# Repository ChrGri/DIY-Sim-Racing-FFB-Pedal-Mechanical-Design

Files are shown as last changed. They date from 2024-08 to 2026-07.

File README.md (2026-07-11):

<p align="center">
  DIY Sim Racing FFB Pedal Banner
</p>

# DIY-Sim-Racing-FFB-Pedal-Mechanical-Design
If you're used to standard spring or damper-based pedals with rumble motors attached, a force-feedback pedal is the next step. It uses a high power servo attached to a linear rail to control the motion of the pedal. This allows you to change how the pedal feels with a few changes on your PC, whether that's braking pressure, response or travel or the thottle weight or stiffness. You can even use profiles to build different "feels" for different cars, switching profiles between cars to give each vehicle a different driving experience. Additionally, since the pedal movement is controlled, the feedback it can produce is totally different - imaging feeling ABS feedback moving the pedal, the kick of the gear change through the throttle or feedback from road bumps through the pedals. It's an experience like no other! If that sounds like something you want to build for yourself, then read on! This project documents people who want to design and/or build their own force-feedback pedal. 

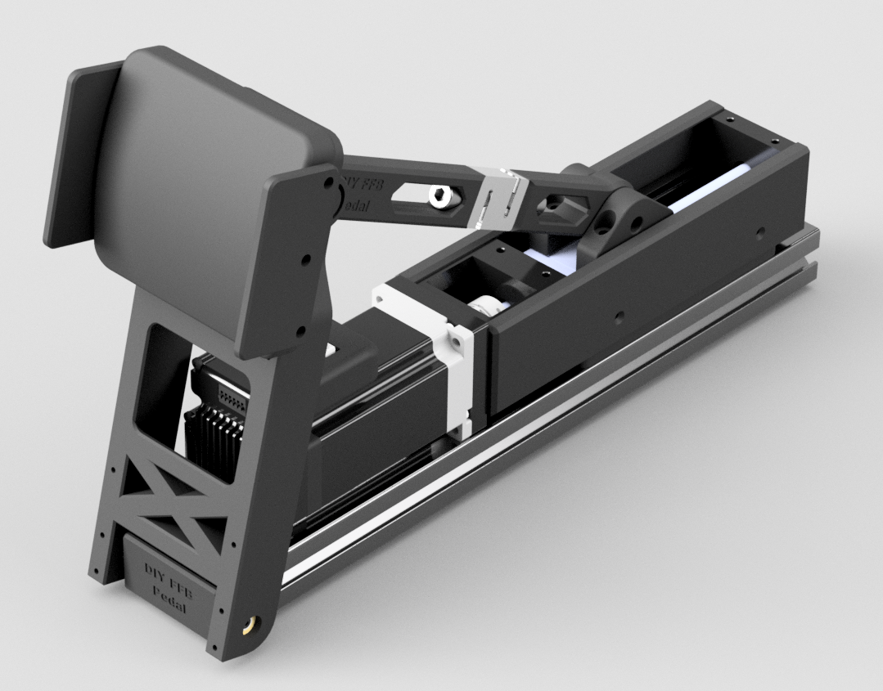
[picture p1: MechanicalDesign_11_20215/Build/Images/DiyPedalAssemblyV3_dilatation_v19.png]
Current iteration of pedal design, using more expensive components, such as JKK60 linear rails, DYLY-107 loadcell, 3080 aluminium profile <br> .

The current iteration of the electronics are depicted below <br>
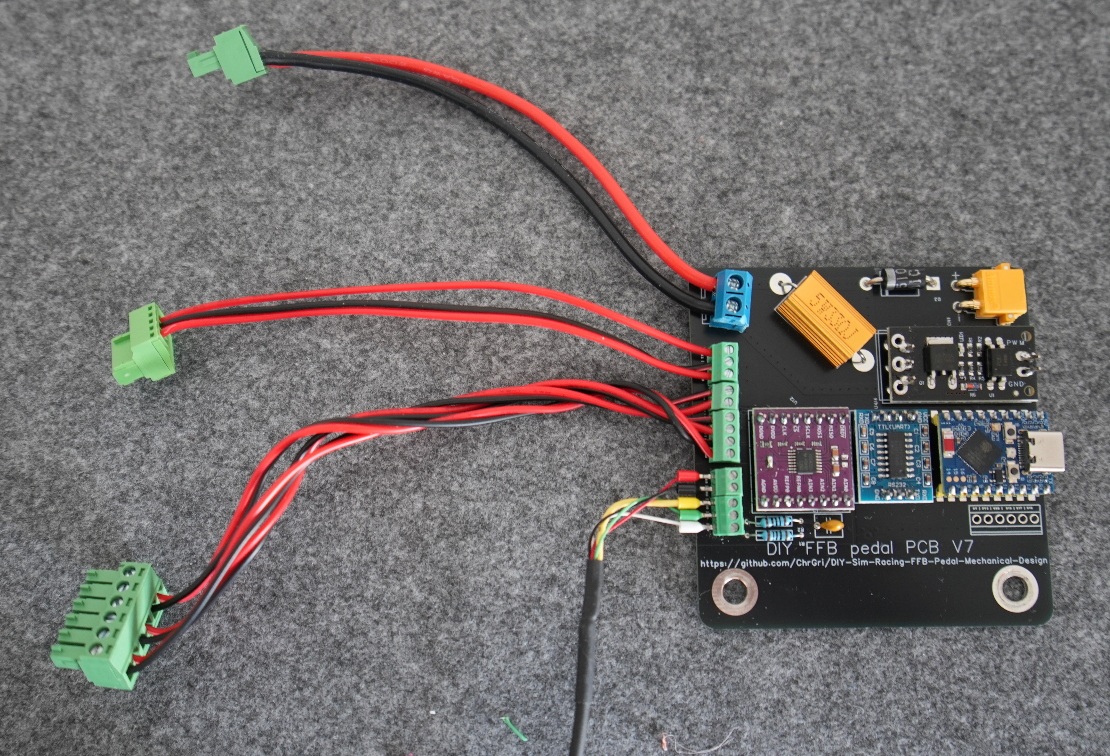
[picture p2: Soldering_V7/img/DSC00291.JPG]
.

This is V7 of the PCB design and compared to previous versions, it offers
- better loadcell reading signal-to-noise-ratio (SNR) due to RC-filter design and better wire routing
- smaller form factor
- lower costs (since ESP32 S3 zero/mini is cheaper)
- better wire management.

> [!TIP]
> **Disclaimer** This repository documents my research progress. I wanted to understand the necessary signal processing and control theory algorithms behind such a device. 

> [!WARNING]
> The FFB pedal is a robot and can be dangerous. Please watch [The Terminator](https://en.wikipedia.org/wiki/The_Terminator) before continuing. If not interacted with care, it may cause harm. I'm not responsible for any harm caused by this design suggestion. Use responsibly and at your own risk.

# Project repositories
This project has been divided into multiple repositories, each with differt purposes. The mechanical design repository provides the information you need to build the mechanics of ChrGri's pedal. It's not the only design, but it's strong and reliable. There are more options on the Wiki, and you can find even more designs on the Discord server. The Software repo (this repo) discusses how to select, order and connect the electronics, flash the firmware and get the pedal up and running. The final repo, contains designs for the recommended circuit boards that control the pedal.
| Description           |  Link |
:------------------------- | :------------------------- |
| ChrGri's mechanical and electrical design | https://github.com/ChrGri/DIY-Sim-Racing-FFB-Pedal-Mechanical-Design |
| Software (firmware, SimHub plugin, ...) |https://github.com/ChrGri/DIY-Sim-Racing-FFB-Pedal |
| Control Board and Power Board design | https://github.com/gilphilbert/DIY-Sim-Racing-FFB-Pedal-PCBs |

# Support the team
We :heart: doing research. New hardware (e.g. oscilloscopes, logic analyzers, servos, PCBs) is very expensive. Feel free to support us and thus fasten up the research activity.

Dev | captainchris | tcfshcrw | gilphilbert
--- | --- |--- |-- 
Buy me a coffee |  |  |    | 
Ko-fi |  | |   |

# License
Shield: [][cc-by-nc-sa]

This work is licensed under a
[Creative Commons Attribution-NonCommercial-ShareAlike 4.0 International License][cc-by-nc-sa].

[][cc-by-nc-sa]

The reason for that license selection is that at some point in time, individuals start
- to steal the sources and binaries and sell them on the internet
- mass production of FFB pedals in their living rooms to make money by taking parts from this project and Simucubes design files.
  
All that, without contributing anything to this project.

[cc-by-nc-sa]: http://creativecommons.org/licenses/by-nc-sa/4.0/
[cc-by-nc-sa-image]: https://licensebuttons.net/l/by-nc-sa/4.0/88x31.png
[cc-by-nc-sa-shield]: https://img.shields.io/badge/License-CC%20BY--NC--SA%204.0-lightgrey.svg

# BOM
The price of one pedal is about 250€-400€. <br>
The electronics BOM can be found [here](BOM/Electronics/README.md). <br>
The mechanical design BOM can be found [here](BOM/Mechanics/README.md).

# Assembly steps
1. Order of PCB --> [here](PcbOrder)
2. Mechanical assembly --> [here](MechanicalDesign_11_20215/Build/Assemlby_PedalArm.md)
3. Electronical assembly --> [here](Soldering_V7)
4. Software finalization --> [here](FinalizingSoftware).

# Hardware features
For the interessted reader, some deeper analysis can be found [here](Features).

## Star History
<a href="https://star-history.com/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">
  Star History Chart
</a>

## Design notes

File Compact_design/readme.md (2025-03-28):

# COMPACT PEDAL DESIGN
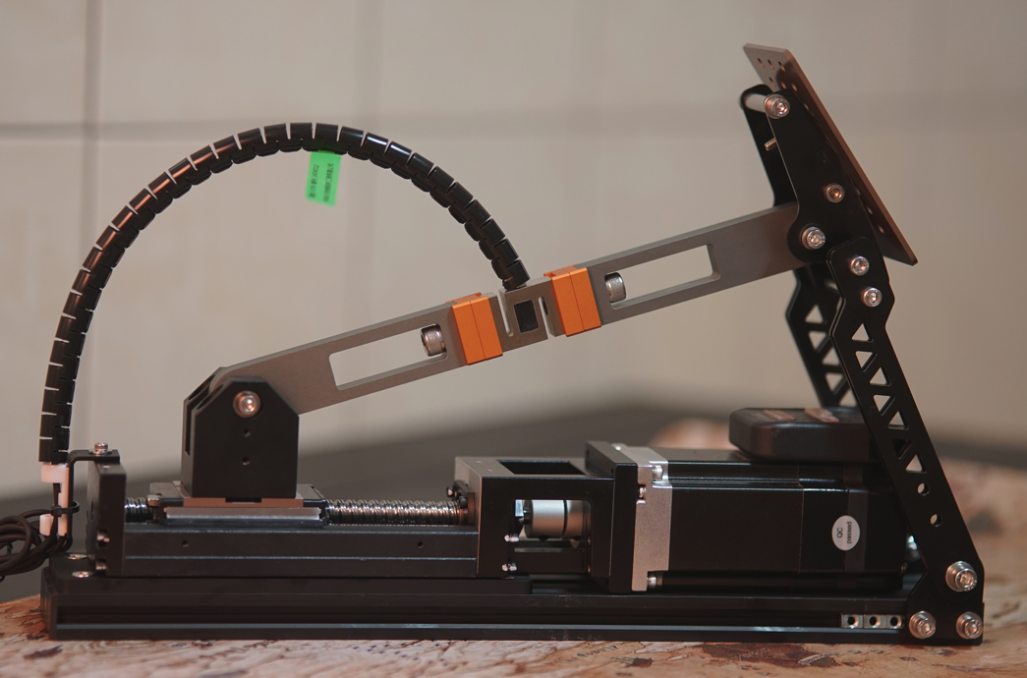
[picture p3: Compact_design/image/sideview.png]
<br>
This is the design minimizing the pedal width with 2060 profile.<br>
The minimum width of pedal without screw is about 73mm. Total Length is 400mm.<br>

## CAD MODEL
The CAD model is in [HERE](./CAD/FFB_PEDAL_2060_COMPACT_DESIGN.stp).<br>
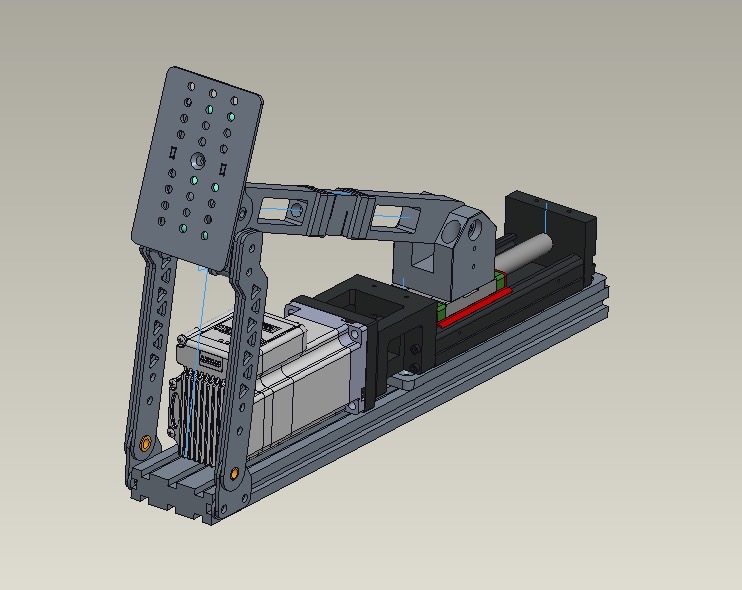
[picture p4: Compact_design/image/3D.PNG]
<br>
Exploded view.<br>
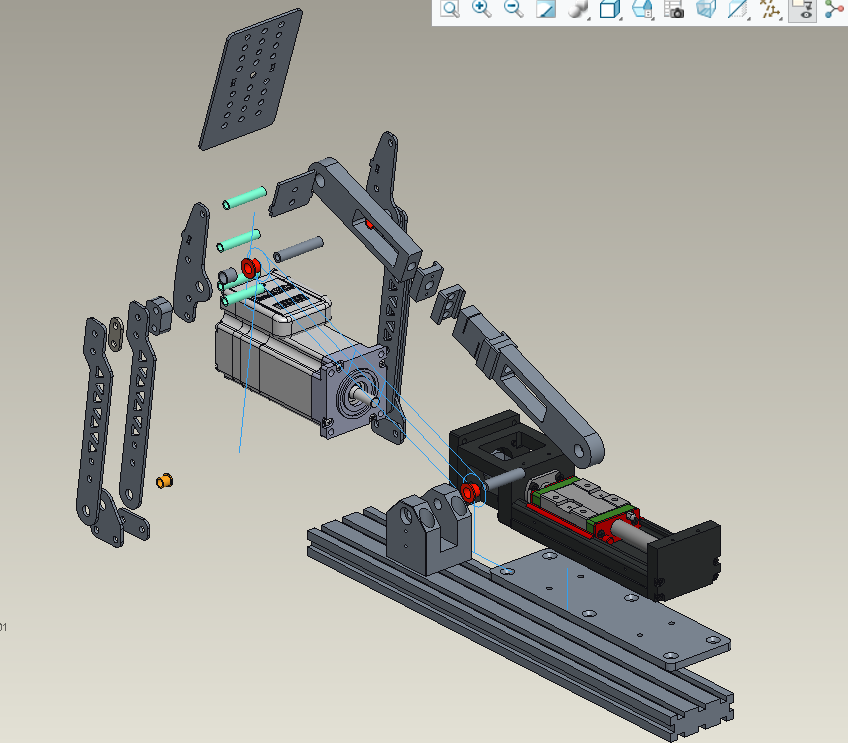
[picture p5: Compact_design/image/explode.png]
<br>
some basic parameter for pedal kinemaatics:<br>
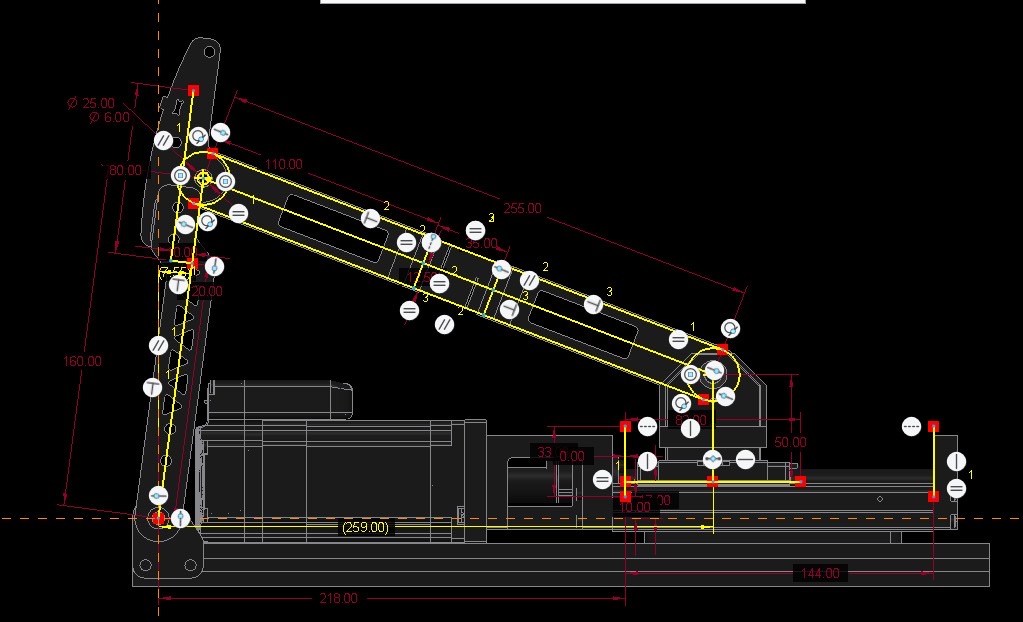
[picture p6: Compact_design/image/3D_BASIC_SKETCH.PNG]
<br>
## BOM
### MANUFACTURE-CNC
The design is including CNC process to create the pedal, you need separate them from 3D CAD in above.
Related file can be found here:
| PART            | CAD FILE |DRAWING FILE |THREAD | MATERIAL| QUANTITY| |
:------------------------- |  :------------------------- |  :------------------------- | :------------------------- |:------------------------- |:------------------------- |:------------------------- |
| PIVOT-BRKT-JKK |[LINK](./CAD/PIVOT-BRKT-JKK.stp)| [LINK](./CAD/pivot-brkt-jkk.pdf)|V |AL6061 T6 | 1 ||
| JKK-2060-ADAPTER | [LINK](./CAD/JKK-2060-ADAPTER.stp)|[LINK](./CAD/jkk-adapter-2060.pdf)|V |AL6061 T6 | 1 ||
| SPACER-2-HOLES | [LINK](./CAD/SPACER-2-HOLES.stp)|NA| |AL6061 T6 | 2 |For default 2.3mm sheet material|
| SPACER-2-HOLES-20 | [LINK](./CAD/SPACER-2-HOLES-20.stp)|NA| |AL6061 T6 | 2 |For 2.0mm sheet material|
| SPACER-2-HOLES-25 | [LINK](./CAD/SPACER-2-HOLES-25.stp)|NA| |AL6061 T6 | 2 |For 2.5mm sheet material|
| SPACER-2-HOLES-30 | [LINK](./CAD/SPACER-2-HOLES-30.stp)|NA| |AL6061 T6 | 2 |For 3.0mm sheet material|
| 5MM-HOLDER-CAP | [LINK](./CAD/5MM-HOLDER-CAP.stp)|NA| |AL6061 T6 | 2 |
| 5MM-HOLDER-THREAD | [LINK](./CAD/5MM-HOLDER-THREAD.stp)|[LINK](./CAD/5mm-holder-thread.pdf)|V |AL6061 T6 | 2 |
| LC-LINK-NEW | [LINK](./CAD/LC-LINK-NEW.stp)|NA| |AL7075 T6 | 2 |
### MANUFACTURE-LASER CUT
The design is including laser cut process to create the pedal, you need send the dwg file to laser cut supplier.<br>
Laser-cut manufacture file: [DWG LINK](./CAD/laser-cut-dwg.dwg), [PDF LINK](./CAD/laser-cut-dwg.pdf)<br>
Material can be SUS304 or SUS420J2, if you prefer SUS420J2, please apply heat treatment(HRC36-40) after laser cutting.<br>
Sheet thickness default is 2.3mm. You can also modify to 2.0/2.5/3.0mm, but should replace SPACER-2-HOLES to the corresponding CAD model.<br>
| PART            |  QUANTITY|
:------------------------- | :------------------------- |
| BRKT-PLATE_WIDE | 1 |
| PEDAL-PLATE-BRKT | 1 |
| PEDAL-ARM-2 |  2 |
| PEDAL-ARM |  4 |
| COLLAR-TWIN-5 |  2 |
| PIVOT-BRKT-SPACER |  2 |
| PIVOT-PLATE |  2 |

Please note after laser cutting, the BRKT-PLATE_WIDE should apply the countersunk by drill.<br>
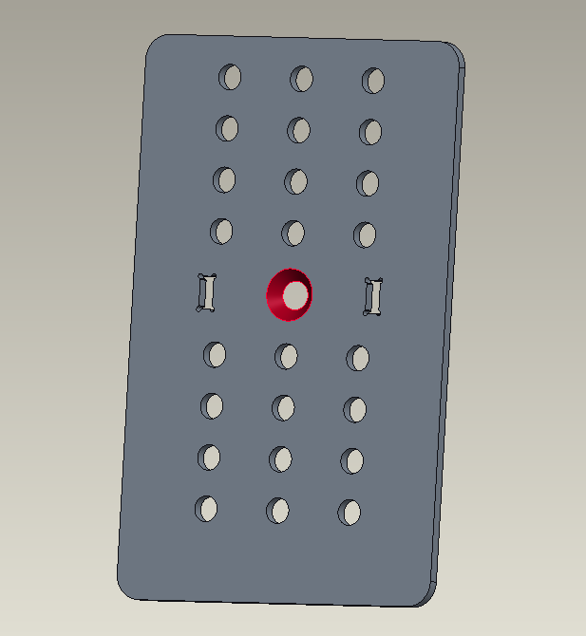
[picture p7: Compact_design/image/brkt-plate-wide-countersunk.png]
<br>
Please also note, all the connect holes should remove the burrs on the laser starting and end point.<br>
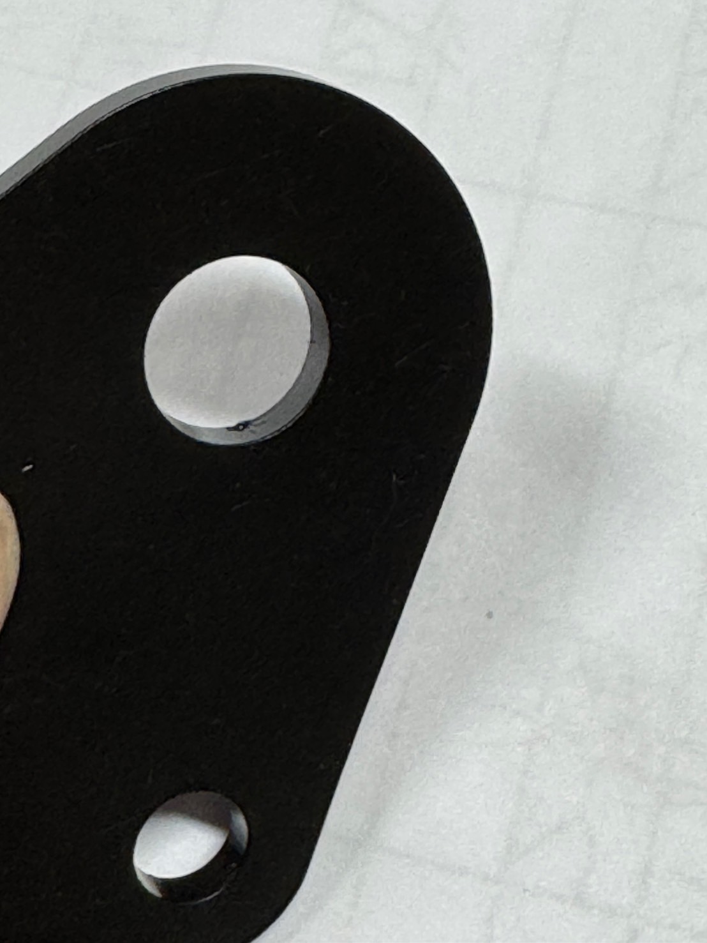
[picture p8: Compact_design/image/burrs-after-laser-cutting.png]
<br>
### PURCHASED PARTS
| PART            |  QUANTITY| LINK|
:------------------------- | :------------------------- | :------------------------- |
| isv57t-130s | 1 |[Stepperonline](https://www.omc-stepperonline.com/nema-23-integrated-easy-servo-motor-130w-3000rpm-0-45nm-63-73oz-in-20-50vdc-servo-motor-short-shaft-isv57t-130s) |
| JKK60-5-C-150-A1-F4 Rail | 1 |[JLC](https://jlcmc.com/product/s/B16/BQD-JKK60/steel-linear-actuators--kk60-series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) |
| Stainless Steel Internal Thread Round Head Cylindrical Pin M5x8x35 | 5 |[AliExpress](https://www.aliexpress.com/item/3256805881962694.html) |
| Stainless Steel Internal Thread Round Head Cylindrical Pin M5x8x40 | 1 |[AliExpress](https://www.aliexpress.com/item/3256805881962694.html) |
| Flange Self Lubricating Bearing 8X10X8-15X1.2 | 4 |[AliExpress](https://www.aliexpress.com/item/1005007192252292.html) |
| Flange Self Lubricating Bearing 6X8X8-12X1 | 2 |[AliExpress](https://www.aliexpress.com/item/1005007192252292.html) |
| Stainless Steel (A2-70) Bushing Washer Round Hollow Unthreaded Stand-off Spacer D10xM8 L9mm | 2 |[AliExpress](https://www.aliexpress.com/item/1005008191841149.html) |
| 2060 AL Profiles  Length 400mm|  1 | |
| T-NUT for 20 series profile |  16 | |
| Coupler ID8 OD25 L30 |  1 | |
| M4x16 HEX Screw |  4 | |
| M6x20 HEX Screw |  2 | |
| M5x8 HEX Screw |  4 | |
| M5x10 HEX Screw |  8 | |
| M5x12 HEX Screw |  4 | |
| M5x25 HEX Screw |  4 | |
| M5x35 HEX Screw |  4 | |
| M3x6 HEX Screw |  4 | |
| M8x25 HEX Screw |  2 | |
| M5x20 countersunk Screw |  1 | |
| M5x12 countersunk Screw |  6 | |
| M5 Nut |  1 | |
| M5 Spring Washer |  12 | |
| M5 Washer OD 10 |  12 | |
| M6 Nut |  2 | |
| M6 Spring Washer |  2 | |
| M6 Washer |  2 | |

## 2080 Design
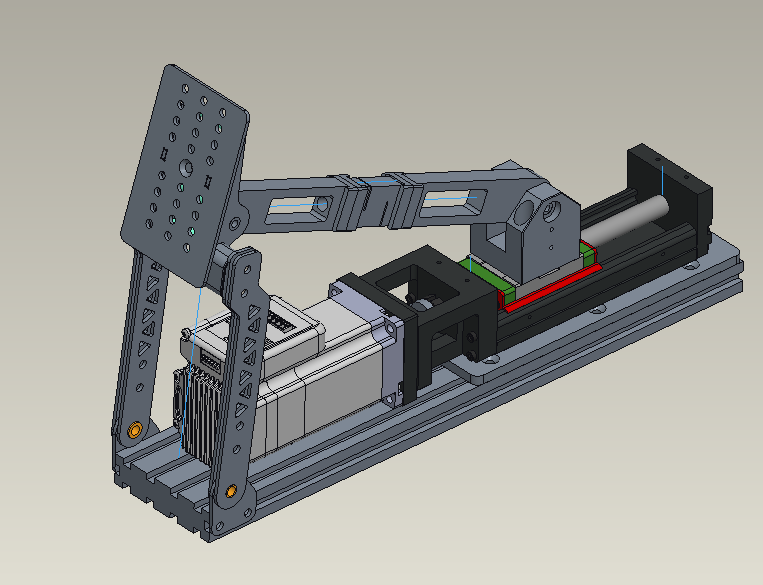
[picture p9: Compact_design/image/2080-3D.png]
<br>
If you prefer the design with 2080 base extrusion, please replace the spacer and adapter in below with crossponding sheet thickness.<br>
Assembly link: [LINK](./CAD/2080-stp/ap-asm-2080_asm.stp)
| PART            | CAD FILE |DRAWING FILE |THREAD | MATERIAL| QUANTITY| |
:------------------------- |  :------------------------- |  :------------------------- | :------------------------- |:------------------------- |:------------------------- |:------------------------- |
| JKK-2080-ADAPTER | [LINK](./CAD/2080-stp/jkk-2080-adapter.stp)|[LINK](./CAD/2080-stp/jkk-adapter-2080.pdf)|V |AL6061 T6 | 1 ||
| SPACER-2-HOLES | [LINK](./CAD/2080-stp/spacer-2-holes-2080.stp)|NA| |AL6061 T6 | 2 |For default 2.3mm sheet material|
| SPACER-2-HOLES-20 | [LINK](./CAD/2080-stp/spacer-2-holes-20-2080.stp)|NA| |AL6061 T6 | 2 |For 2.0mm sheet material|
| SPACER-2-HOLES-25 | [LINK](./CAD/2080-stp/spacer-2-holes-25-2080.stp)|NA| |AL6061 T6 | 2 |For 2.5mm sheet material|
| SPACER-2-HOLES-30 | [LINK](./CAD/2080-stp/spacer-2-holes-30-2080.stp)|NA| |AL6061 T6 | 2 |For 3.0mm sheet material|

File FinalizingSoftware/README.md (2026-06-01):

# Flashing the ESP32
> [!WARNING]
> Flashing the firmware before connecting the 36V power is crucial, since the ESPs GPIOs can be in undefined state otherwise, resulting in damage of the periphery, e.g. brake resistor. 

Now make sure you test your electronics! Electronics setup and testing is covered in [Electronics Setup](https://github.com/ChrGri/DIY-Sim-Racing-FFB-Pedal/wiki/Electronics-setup) and includes troubleshooting steps.

# Simhub plugin parameterization

## Simhub plugin configuration
When using the PCB and mechanical design from this repo, tune the Simhub plugin as suggested below.

### CDC setting
Working settings with V5 PCB for CDC and DTR/RTS are depicted below <br> 


### Pedal  kinematic
To accurately estimate the pedal force, the controller needs information of the geometric design. Open the **PEDAL-KINEMATIC** tab and adjust the values accordingly. 

#### V1 design
O to A = 215<br>
A to B = 66<br>
O to C = 167<br>
C to D = 0<br>
C to B = 233<br>



#### V2 design
O to A = 225<br>
A to B = 72<br>
O to C = 187<br>
C to D = 0<br>
C to B = 266<br>


The controller will automatically measure the travel distance. If you want it not to hit the max endstop, reduce the travel distance below the acctual travel distance of the sled.

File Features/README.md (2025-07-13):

# Brake resistor investigations
In previous version only a condensator was used to store the servos EMF. Since V5 PCB, a brake resistor circuit was implemented to dissipate the electrical energy, see the dedicated section [here](BrakeResistor). 

# ADC
Some investigations to improve the loadcell reading accuracy have been done. Results are documented [here](ADC).

# Loadcell
Some investigations regarding different loadcel types have been done. Results are documented [here](Loadcell).

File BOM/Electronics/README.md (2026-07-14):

# BOM
Given prices are just indicators. Sellers regularly offer discounted prices, e.g. I paid for the iSV57 60€, for the linear rail 46€.

Disclosure: Some of the links below are affiliate links, which means we may receive a commission at no cost to you if you make a purchase. By using the provided links, you help me buy tools or hardware for further investigations.

## Electronics:

Apart from the mechanical parts, more electronical parts have to be ordered. Please conduct the [software/electronics](https://github.com/ChrGri/DIY-Sim-Racing-FFB-Pedal) repo and the discord for help first, to see if electronic parts are still up to date. 

### Generic parts:
| Part  | Info | Quantity | Price | Primary link | Secondary link | 
| --- | --- | --- | --- | --- | --- |
| iSV57T-130S  | shorter version ("130s") is prefered. If the longer version ("130") is cheaper, buy this and cut the motor shaft to appropriate length with a metal handsaw. Alternatively the 180s servo is a bit stronger and not selled out that often. | 1 piece  | 90€ | [130s link](https://www.omc-stepperonline.com/de/nema-23-integrierter-easy-servo-motor-130w-3000rpm-0-45nm-63-73oz-in-20-50vdc-buerstenloser-dc-servomotor-kurze-welle-isv57t-130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) | [180s link](https://www.omc-stepperonline.com/de/nema-23-integrierter-easy-servo-motor-180w-3000rpm-0-6nm-84-98oz-in-20-50vdc-servomotor-kurze-welle-isv57t-180s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)|
| PSU | 1 PSU can power multiple pedals (2 at least) | 1 piece | 25€ | [link](https://www.omc-stepperonline.com/de/lrs-350-36-mean-well-350w-36vdc-9-7a-115-230vac-geschlossenes-schaltnetzteil-lrs-350-36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) | |
| DYLY‑107 load cell | 50 kg, good signal‑to‑noise ratio | 1 | 50€| [link](https://amzn.to/4ayAk7B) | [link](https://s.click.aliexpress.com/e/_c4c2i6k5)|
| Servo debug port connector  | Female, 5P | 1 piece  | 1€ | [link](https://amzn.to/4uXvVTZ) | [link](https://s.click.aliexpress.com/e/_oCbioHZ) | 

### Control PCB: <br>
The components for the V6 PCB are listed below. 

| Part  | Info | Quantity | Price | Amazon link | Aliexpress link | 
| --- | --- | --- | --- | --- | --- |
| Control PCB | Ordered from JLCPCB | 1 unit per pedal | 8€ | [link](../Wiring/PcbV6/DiyFfbPedalPcbV6.zip) | |
| ESP32 S3  |  | 1 | 13€ | [link](https://amzn.to/4pjNnjq) | [link](https://s.click.aliexpress.com/e/_c3IpHQ4P) |
| ADS1220 |  | 1 unit per pedal | 1€ | [link](https://amzn.to/4eMUyLL) | [link](https://s.click.aliexpress.com/e/_c3NqYwqv) |
| SP2323  |  Single channel 20x16 | 1 | 1€ | [link](https://amzn.to/4e1xEBK) | [link](https://s.click.aliexpress.com/e/_c3BQLhi9) |
| SR5100 Schottky diode | |  1 diode per pedal | 1€ | [link](https://amzn.to/3CmN8jR)| [link](https://s.click.aliexpress.com/e/_DdrrsrJ) |
| FR120N mosfet | 100V | 1 per pedal | 1€ |[link](https://amzn.to/40MX27z) | [link](https://s.click.aliexpress.com/e/_oEP6IpR)|
| 8 or 10 5W resistor | select 10R or 8R | 1 per pedal | 1€ | [link](https://amzn.to/4ujXg1v)| [link](https://s.click.aliexpress.com/e/_c3Zg1NXJ)|
| Wire (AWG 18)  | power wire | 0.2m | 5€ | [link](https://amzn.to/4htGLtR) | [link](https://s.click.aliexpress.com/e/_oke6LFx) |
| Wire (AWG 30)  | to connect the control electronics | 0.2m | 5€ | [link](https://amzn.to/4geYNz0) | [link](https://s.click.aliexpress.com/e/_olWGFI1) |
| 2.54mm pitch screw terminals | 5 pin (2pin + 3pin) for loadcell to board | 1 per pedal | 6€| [link](https://amzn.eu/d/5S0YVBn) | [link](https://s.click.aliexpress.com/e/_c3qY4kDr) |
| XT30 connector angled | | 1 male connector per pedal | | [link](https://amzn.to/4xkNmQ4) | [link](https://s.click.aliexpress.com/e/_c4a68ig9)|
| Pin header | optionally, select female | | 1€| [link](https://amzn.to/4hySFCT) | [link](https://s.click.aliexpress.com/e/_ooJnkBP)|
| 100uF capacitor | Select 104 (0.1uF) | 1 per pedal| 1.35€ per 100PC| [link](https://amzn.to/4fiyDwU) | [link](https://s.click.aliexpress.com/e/_c2yY8p15)|
| 100Ohm resistor | Select 100 Ohm or 100R 1/4 W| 2 per pedal | 1€| [link](https://amzn.to/4yAbtLk) | [link](https://s.click.aliexpress.com/e/_c3TUM20f)|

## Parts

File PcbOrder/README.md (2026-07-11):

# Order PCB
1. Download the control and power PCB, e.g. [control PCB V7](../Wiring/PcbV7/DiyFfbPedalPcbV7.zip)
2. Navigate to https://jlcpcb.com/
3. Upload the gerber files
4. Leave the standard settings (2 layers, FR-4, 1.6mm, PCB color of your choice, see image below), check which delivery options is the cheapest <br>
 <br>
5. Oder the PCB
6. Wait for the delivery. Typically 10 days to europe.

> [!NOTE]
> The proposed PCB is easy to source, but requires manual soldering. The awesome user [gilphilbert](https://github.com/gilphilbert) designed a PCB assembly of the control board which can be found [here](https://github.com/gilphilbert/DIY-Sim-Racing-FFB-Pedal-PCBs) and features the same features as the V6 PCB. It's currently beeing tested. The current status is published on the discord channel.

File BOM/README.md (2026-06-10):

# BOM
Given prices are just indicators. Sellers regularly offer discounted prices, e.g. I paid for the iSV57 60€, for the linear rail 46€.

Disclosure: Some of the links below are affiliate links, which means we may receive a commission at no cost to you if you make a purchase. By using the provided links, you help me buy tools or hardware for further investigations.

## Mechanical parts

### Larger parts
| Part  | Info | Quantity | Price | Amazon link | Aliexpress link | 
| --- | --- | --- | --- | --- | --- |
| SK12  | | 4 pieces  | 4,50€ | [link](https://amzn.to/4fibyZe) | [link](https://s.click.aliexpress.com/e/_DlVHbol) |
| 608zz bearing  | | 2 pieces  | 5€ | [link](https://amzn.to/4grWl92) | [link](https://s.click.aliexpress.com/e/_DC5FMbP) |
| Linear guide  | SFU1610, 100mm stroke | 1 piece  | 60€ | [link](https://a.aliexpress.com/_EJWoX55) | |
| 2080 profile  | 400mm length | 1 piece  | 15€ | [link](https://amzn.to/4glrw63) | [link](https://s.click.aliexpress.com/e/_DEPruwN) |
| M12 ball joint  | All right handed thread | 2 piece  | 11€ | [link](https://amzn.to/3Dqoyyq) | |
| M8 threades rod  |  |  one piece ca. 110mm length | 2€ | local hardware store | [link](https://s.click.aliexpress.com/e/_Dmk4XgV) |
| M12 threades rod  |  | two pieces a 45mm + two pieces a 55mm  | 2€ | local hardware store | [link](https://s.click.aliexpress.com/e/_DCL5p3L) |
| M8 self locking nut  |  | 2 pieces  | 0,50€ | local hardware store |  |
| M5 t-nut  |  | 8 pieces  | 3€ | [link](https://amzn.to/3DhZ1Yi) | [link](https://a.aliexpress.com/_EyKq6Mx) |
| FDM filament  |  | ca. 300g  | 25€ | [link](https://amzn.to/4gbUhly) | |

### Srews/bolts:
| Size  | Info | Quantity | Price | Link |
| --- | --- | --- | --- | --- |
| M4x10mm  | | 8 pieces  | 0,50€ |
| M4x15mm  | | 8 pieces  | 0,50€  |
| M5x10mm  | | 4 pieces  | 0,50€ |
| M5x25mm  | | 4 pieces  | 0,50€ |
| M5x30mm  | | 10 pieces  | 0,50€ |
| M4 washer  | | 4 pieces  | 0,50€ |

## Electronics:

Apart from the mechanical parts, more electronical parts have to be ordered. Please conduct the [software/electronics](https://github.com/ChrGri/DIY-Sim-Racing-FFB-Pedal) repo and the discord for help first, to see if electronic parts are still up to date. 

### Generic parts:
| Part  | Info | Quantity | Price | Primary link | Secondary link | 
| --- | --- | --- | --- | --- | --- |
| iSV57T-130S  | shorter version ("130s") is prefered. If the longer version ("130") is cheaper, buy this and cut the motor shaft to appropriate length with a metal handsaw. Alternatively the 180s servo is a bit stronger and not selled out that often. | 1 piece  | 90€ | [130s link](https://www.omc-stepperonline.com/de/nema-23-integrierter-easy-servo-motor-130w-3000rpm-0-45nm-63-73oz-in-20-50vdc-buerstenloser-dc-servomotor-kurze-welle-isv57t-130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) | [180s link](https://www.omc-stepperonline.com/de/nema-23-integrierter-easy-servo-motor-180w-3000rpm-0-6nm-84-98oz-in-20-50vdc-servomotor-kurze-welle-isv57t-180s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)|
| PSU | 1 PSU can power multiple pedals (2 at least) | 1 piece | 25€ | [link](https://www.omc-stepperonline.com/de/lrs-350-36-mean-well-350w-36vdc-9-7a-115-230vac-geschlossenes-schaltnetzteil-lrs-350-36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) | |
| Loadcell  | 50kg or 100kg | 1 piece  | 20€ | [link](https://amzn.eu/d/0erHqGqH) | [link](https://s.click.aliexpress.com/e/_DlBk3oV) |
| Servo debug port connector  | Female, 5P | 1 piece  | 1€ | [link](https://s.click.aliexpress.com/e/_oCbioHZ) | | 

### Control PCB: <br>
The components for the V6 PCB are listed below. 

| Part  | Info | Quantity | Price | Amazon link | Aliexpress link | 
| --- | --- | --- | --- | --- | --- |
| Control PCB | Ordered from JLCPCB | 1 unit per pedal | 8€ | [link](../Wiring/PcbV6/DiyFfbPedalPcbV6.zip) | |
| ESP32 S3 waveshare  | 8MB-Not Soldered | 1 | 13€ | [link](https://amzn.to/3CbEBAg) | [link](https://s.click.aliexpress.com/e/_c3Dl2Mwt) |
| ADS1220 |  | 1 unit per pedal | 1€ | [link](https://amzn.to/4eMUyLL) | [link](https://s.click.aliexpress.com/e/_c3NqYwqv) |
| SP2323  |  Single channel 20x16 | 1 | 1€ | [link](https://amzn.to/4e1xEBK) | [link](https://s.click.aliexpress.com/e/_c3BQLhi9) |
| SR5100 Schottky diode | |  1 diode per pedal | 1€ | [link](https://amzn.to/3CmN8jR)| [link](https://s.click.aliexpress.com/e/_DdrrsrJ) |
| FR120N mosfet | 100V | 1 per pedal | 1€ |[link](https://amzn.to/40MX27z) | [link](https://s.click.aliexpress.com/e/_oEP6IpR)|
| 8 or 10 5W resistor | select 10R or 8R | 1 per pedal | 1€ | [link](https://amzn.to/4ujXg1v)| [link](https://s.click.aliexpress.com/e/_c3Zg1NXJ)|
| Wire (AWG 18)  | power wire | 0.2m | 5€ | [link](https://amzn.to/4htGLtR) | [link](https://s.click.aliexpress.com/e/_oke6LFx) |
| Wire (AWG 30)  | to connect the control electronics | 0.2m | 5€ | [link](https://amzn.to/4geYNz0) | [link](https://s.click.aliexpress.com/e/_olWGFI1) |
| 2.54mm pitch screw terminals | 5 pin (2pin + 3pin) for loadcell to board | 1 per pedal | 6€| [link](https://amzn.eu/d/5S0YVBn) | [link](https://s.click.aliexpress.com/e/_c3qY4kDr) |
| XT30 connector angled | | 1 male connector per pedal | | [link](https://amzn.to/4xkNmQ4) | [link](https://s.click.aliexpress.com/e/_c4a68ig9)|
| Pin header | optionally, select female | | 1€| [link](https://amzn.to/4hySFCT) | [link](https://s.click.aliexpress.com/e/_ooJnkBP)|

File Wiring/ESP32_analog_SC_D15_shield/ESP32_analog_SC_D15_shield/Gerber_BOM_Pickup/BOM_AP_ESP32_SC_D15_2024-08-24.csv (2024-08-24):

ID | Name | Designator | Footprint | Quantity | Manufacturer Part | Manufacturer | Supplier | Supplier Part | Price | JLCPCB Part Class
1 | 100nF | C1 | C0805 | 1 | CC0805KRX7R9BB104 | YAGEO(国巨) | LCSC | C49678 | 0.004 | Basic Part
2 | 10uF | C2 | C0805 | 1 | CL21A106KAYNNNE | SAMSUNG(三星) | LCSC | C15850 | 0.01 | Basic Part
3 | 4.7kΩ | R1,R2,R3 | R0402 | 3 | 0402WGF4701TCE | UNI-ROYAL(厚声) | LCSC | C25900 | 0.001 | Basic Part
4 | MCP4728-E/UN | U1 | MSOP-10_L3.0-W3.0-P0.50-LS5.0-TL | 1 | MCP4728-E/UN | MICROCHIP(美国微芯) | LCSC | C108207 | 2.109 | Extended Part
5 | Vin_sel | U2,U6 | HDR-TH_3P-P2.54-V-M-A | 2 | Jumper3 | null | LCSC | C2940050 |  | Extended Part
6 | ESP32-DEVKIT-V1-30PIN COPY 00.2 | 2 | ESP32-DEVKITV1_ESP32-DEVKITV1 | 1
7 | Z-SUBDRBF607A002 | DSUB1 | DSUB-TH_Z-SUBDRBF607A002 | 1 | Z-SUBDRBF607A002 | Nextron(台湾正凌) | LCSC | C235817 | 0.691 | Extended Part
8 | U-USBAR04P-F201 | USB3 | USB-A-TH_U-USBAR04P-F201 | 1 | U-USBAR04P-F201 | Ckmtw(灿科盟) | LCSC | C386741 | 0.301 | Extended Part
9 | _ | USB_SC1,USB_SC2 |  | 2

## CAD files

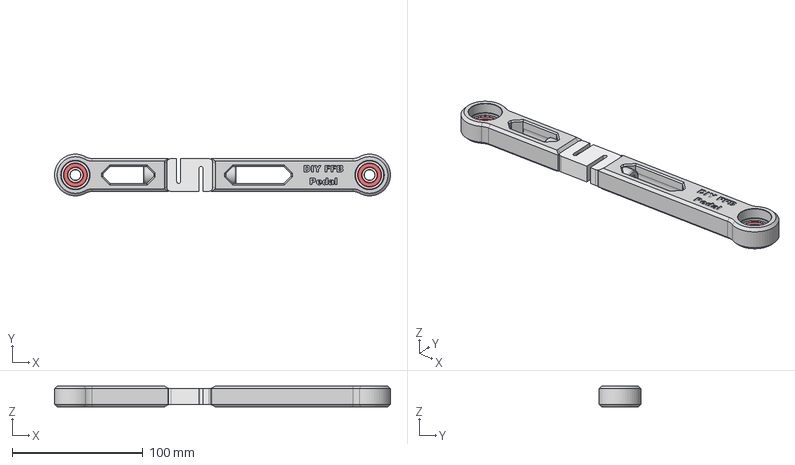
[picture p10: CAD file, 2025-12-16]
CAD/DYLY_107_loadcell_arm/DYLY-107_Loadcell_Arm v47.step
257.0 x 32.0 x 16.0 mm
DYLY-107
Ball 001 x 2
Ball 002 x 2
Ball 003 x 2
Ball 004 x 2
Ball 005 x 2
Ball 006 x 2
Ball 007 x 2
Outer Ring001 x 2
Inner Ring001 x 2
Seal 001 x 2
Seal 002 x 2
Cage 001 x 2
Cage clone 002 x 2
Rivet 002 x 2
Rivet 001 x 2
Rivet 007 x 2
Rivet 006 x 2
Rivet 005 x 2
Rivet 004 x 2
Rivet 003 x 2
BSHCS ANSI B18.3.1M - M8x1.25 x 16 Stahlklasse 2 Einfach x 2

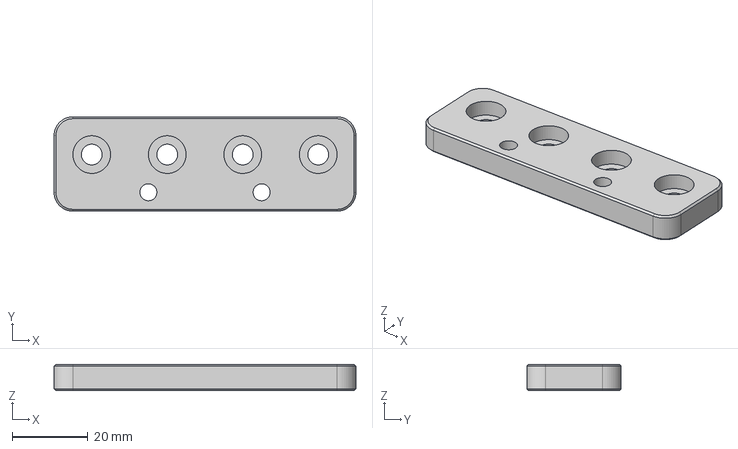
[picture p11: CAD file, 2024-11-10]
CAD/JKK_rail/JKK60_RailTo2080ProfileAdapter v5.step
80.0 x 25.0 x 7.00 mm

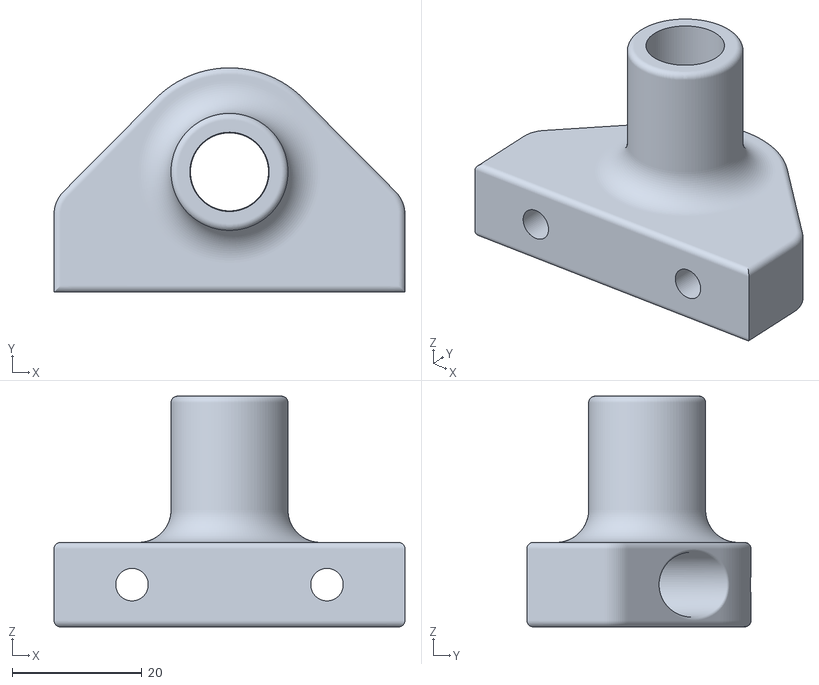
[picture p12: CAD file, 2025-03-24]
CAD/JKK_rail_chris/JKK60_WithCover_RailAdapter_12mm v9.stl
54.0 x 34.5 x 35.5

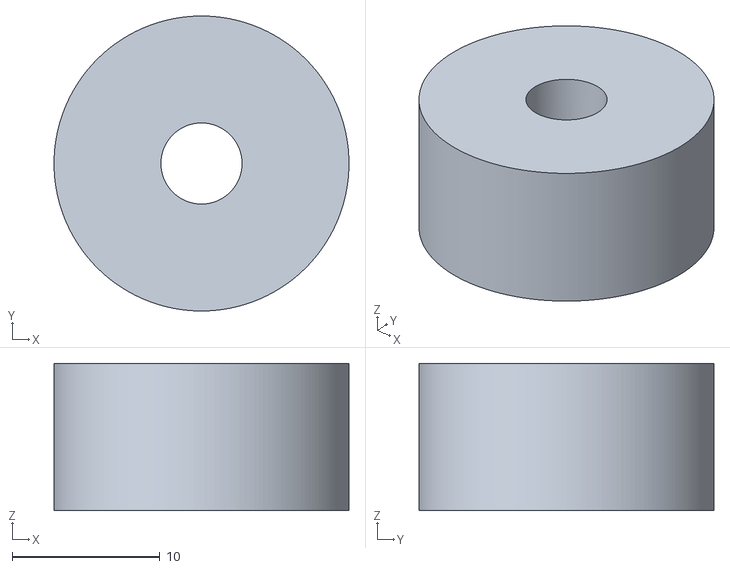
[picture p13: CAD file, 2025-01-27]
CAD/PcbV5Adapter/PcbSpacer v1.stl
20.0 x 20.0 x 10.0

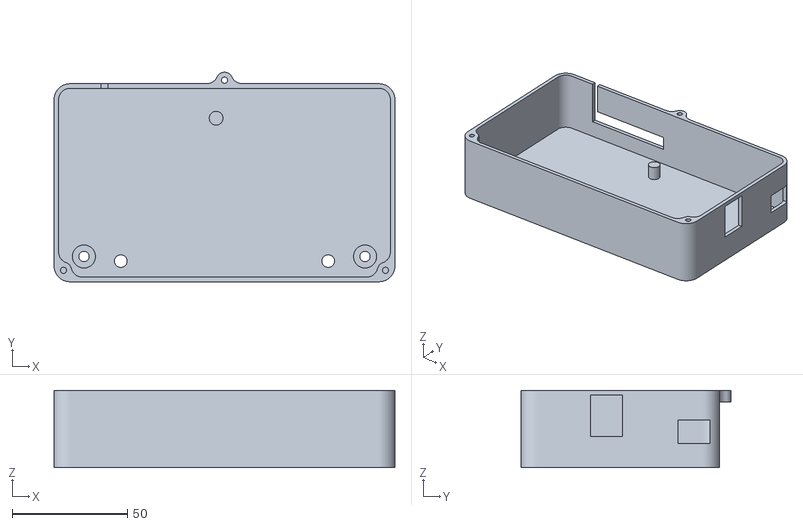
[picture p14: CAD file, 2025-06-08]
CAD/PcbV5case/V5PcbCaseLowerPart.stl
148.0 x 91.0 x 33.6

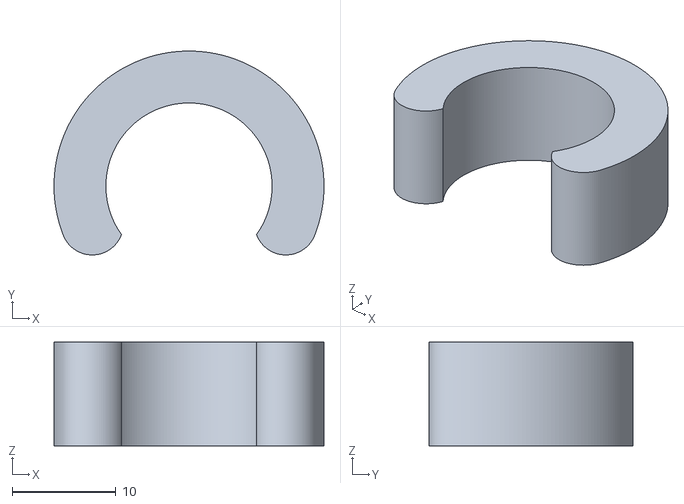
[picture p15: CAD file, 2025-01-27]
CAD/SFU16_spacer v0.stl
26.0 x 19.6 x 10.0

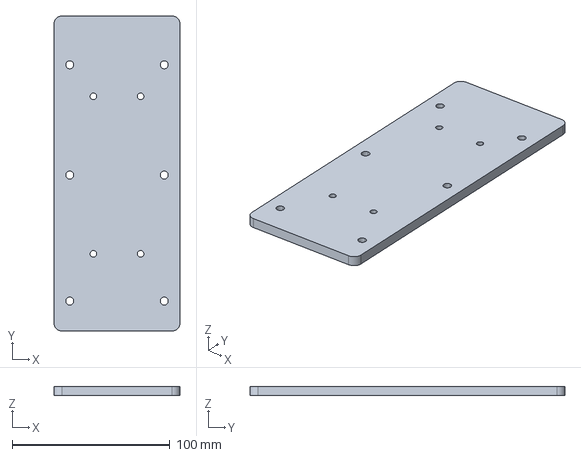
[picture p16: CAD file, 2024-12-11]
Compact_design/CAD/2080-stp/jkk-2080-adapter.stp
80.0 x 200.0 x 6.00 mm

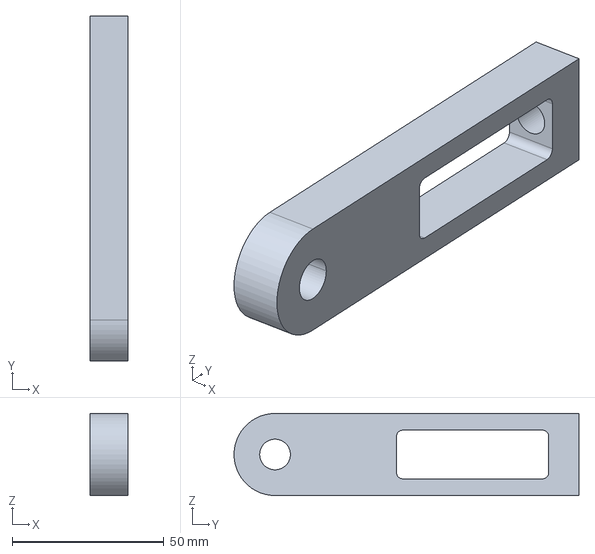
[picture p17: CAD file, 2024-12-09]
Compact_design/CAD/LC-LINK-NEW.stp
12.6 x 113.5 x 27.0 mm

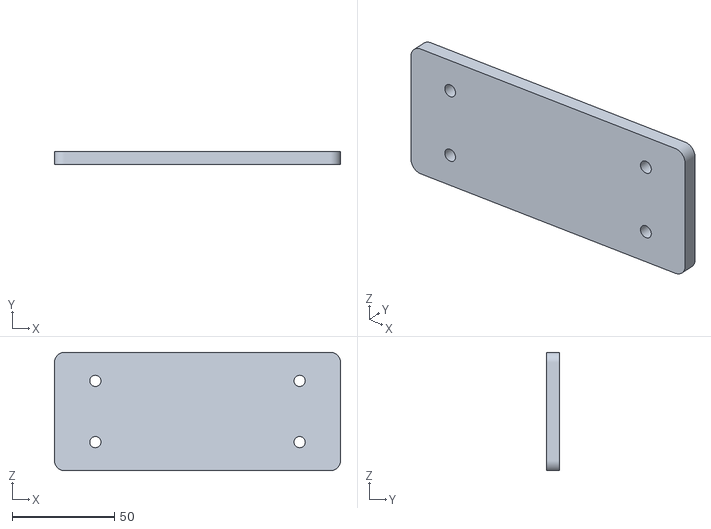
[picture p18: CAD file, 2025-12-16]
MechanicalDesign_11_20215/Build/STL/3060_adapter/JKK60_to_3060_adapter.stl
140.0 x 6.50 x 58.0

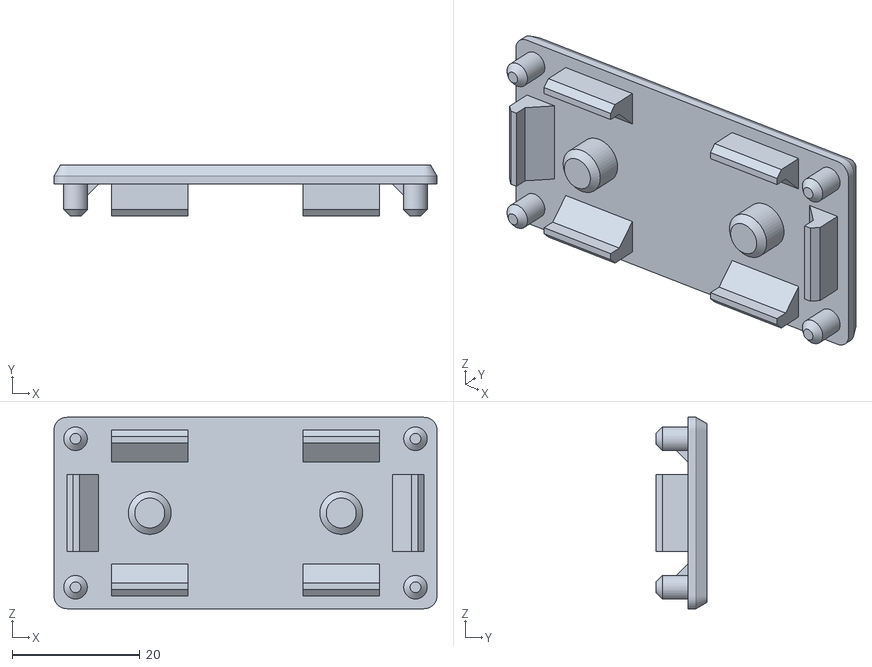
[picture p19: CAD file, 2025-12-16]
MechanicalDesign_11_20215/Build/STL/3060EndCover/3060_cover.stl
60.0 x 8.00 x 30.0

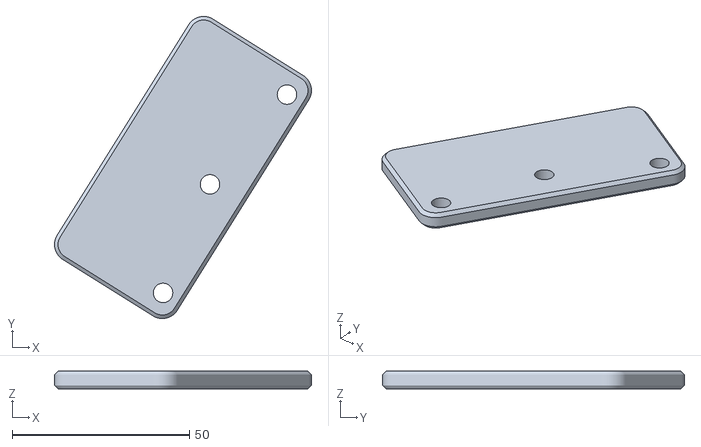
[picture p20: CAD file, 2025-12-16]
MechanicalDesign_11_20215/Build/STL/Faceplate/SideGuard.stl
72.5 x 85.3 x 5.00

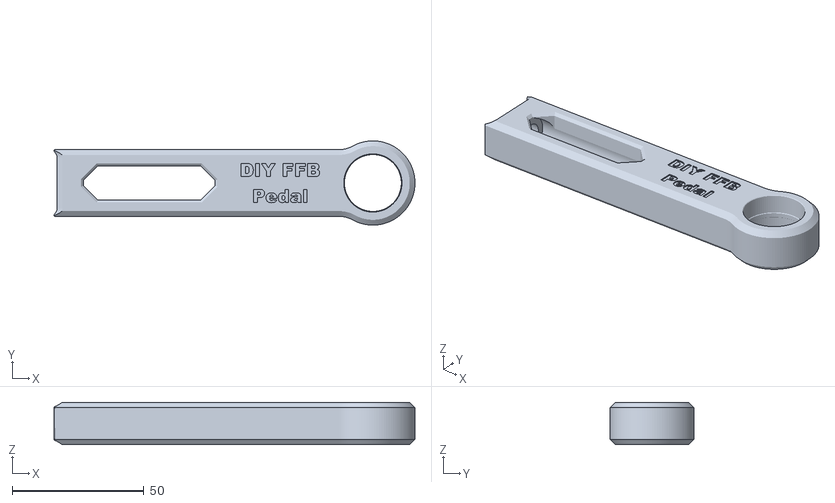
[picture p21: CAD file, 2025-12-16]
MechanicalDesign_11_20215/Build/STL/LoadcellArm/Loadcell-Arm-Front.stl
137.2 x 32.0 x 16.0

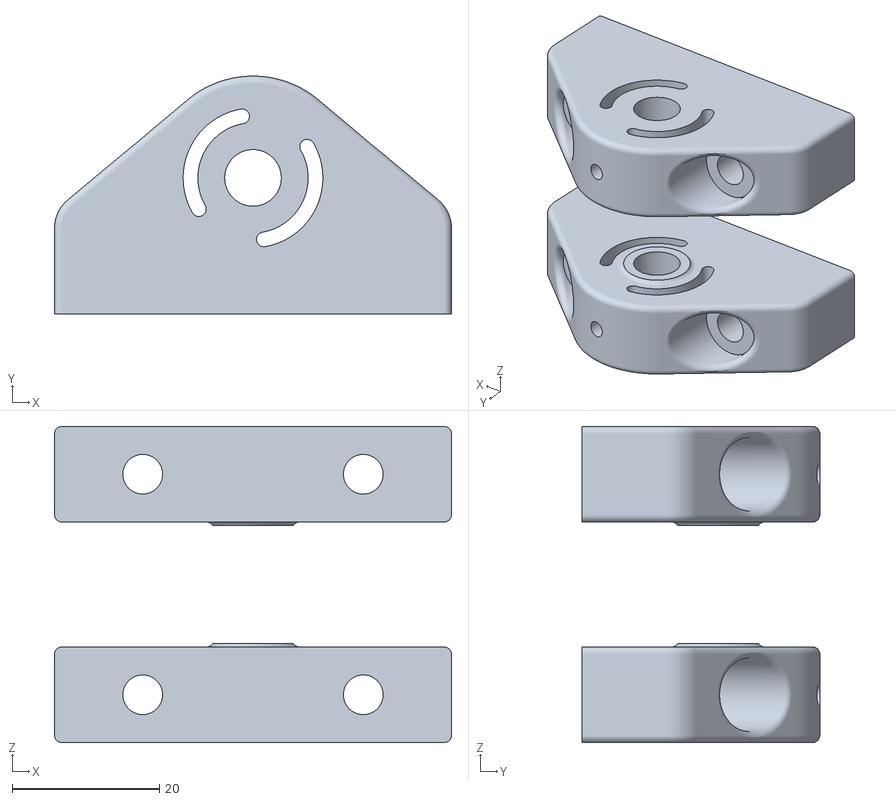
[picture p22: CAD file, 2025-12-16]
MechanicalDesign_11_20215/Build/STL/LowerLoadcellArmAdapter/8mmLowerAdapter_v3.stl
54.0 x 32.3 x 43.0

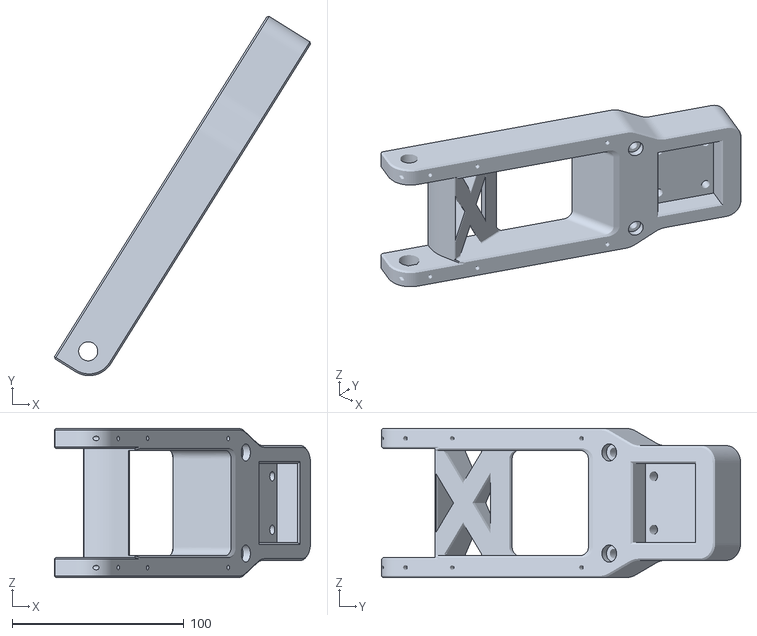
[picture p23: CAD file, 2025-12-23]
MechanicalDesign_11_20215/Build/STL/PedalArm/PedalArm.stl
148.9 x 209.0 x 86.8

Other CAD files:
MechanicalDesign_11_20215/Build/STL/PcbSpacer/PcbSpacer v1.stl
MechanicalDesign_11_20215/Build/STL/RailCover/Cover_left.stl
MechanicalDesign_11_20215/Build/STL/UpperLoadcellArmAdapter/8mmUpperAdapter v4.stl
STL/8mmUpperAdapter v3.stl
CAD/JKK_rail/JKK60_RailTo2080ProfileAdapter v5.f3d
CAD/JKK_rail/JKK60_RailTo2080ProfileAdapter v5.obj
CAD/JKK_rail/JKK60_WithCover_RailAdapter_12mm v9.f3d
CAD/JKK_rail/JKK60_WithCover_RailAdapter_12mm v9.obj
CAD/JKK_rail/JKK60_WithCover_RailAdapter_12mm v9.step
CAD/JKK_rail_chris/JKK60_WithCover_RailAdapter_12mm v9.f3d
CAD/JKK_rail_chris/Jkk_to_2080_adapter v1.f3d
CAD/JKK_rail_chris/Jkk_to_2080_adapter v1.stl
CAD/PSU/LRS_Holder.f3d
CAD/PcbV5Adapter/PcbSpacer v1.f3d
CAD/PcbV5case/V5PcbCaseUpperPart.stl
CAD/PcbV5case/V5_PCB_case v14.f3d
Compact_design/CAD/2080-stp/spacer-2-holes-20-2080.stp
Compact_design/CAD/2080-stp/spacer-2-holes-2080.stp
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

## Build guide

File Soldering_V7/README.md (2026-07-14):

# Soldering tips

A good soldering iron makes your life easier. I like [TS80](https://s.click.aliexpress.com/e/_olD6hiU) and [TS101](https://s.click.aliexpress.com/e/_opJpOtW) soldering irons. 

Soldering tips can be found [here](https://www.youtube.com/watch?v=DfC5FBsud7o).

# Soldering

Please see [BOM](../BOM/Electronics/README.md) for required parts. Some photos from the below assembly have been taken from the old V6 PCB design but apply similarly to V7 PCB design. The final assembly will look like this <br>
. <br>
Feel free to inspect this image whenever beeing unsure. Furthermore, there is a silk screen on the PCB to assist you finding the correct parts orientation.

All steps of the electronics assembly have been documented in sequence below: <br>

[1. Power ciruit](1-PowerCircuit) <br>
[2. SP3232 assembly](2-SP3232) <br>
[3. ADS1220 assembly](3-ADS1220) <br>
[4. RC-Filter](4-RC_Filter) <br>
[5. Wiring](5-Wiring) <br>
[6. Finalizing the electronics](6-Connection) <br>

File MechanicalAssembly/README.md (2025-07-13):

# Motivation
Originally, I built my DIY FFB pedal from metal parts. After using it some time, I got curious whether I can come up with a mechanical design that can be mostly 3d printed and is still rigid enough to withstand the heavy loads accuring in simracing. Furthermore, I wanted to reduce the weight of the components, hopefully seeing a positive impact in the pedal response time. This repo documents the journey of doing that.

The 3D printed design is in use since 07/2024 and doesn't show any signs of wear on my side. 

# Problem
Usually metal is much stronger than plastic and FDM 3d printed parts are weaker than injection molded counterparts. 

# Solution
Create a mechanical design, which takes into account the weaknesses of using FDM 3d printed pedal parts and make them strong at weak spots.

Here is a description of the design choices:

To minimize torsional force on the vertical pedal arms arising through pedal activation, the upper loadcell joint is placed at similar height as the pedal face plate centrum. A deeper analysis of the pedal kinematics can be found [here](https://github.com/ChrGri/DIY-Sim-Racing-FFB-Pedal/wiki/Pedal-kinematic).

Since the upper loadcell joint is located rather high, a SFU1610 spindle with 10mm pitch was selected to allow fast pedal movement. Lower pitch spindle could provide more torque and thus axial force but at the cost of reduced movement speed. Also, the SFU1610 spindle typically emmits less noise and feel smother than 1605 spindles.

The linked linear guide was selected, since it has 30mm M4 bold pattern, which works perfectly fine with the SK12 blocks (32mm spacing, 6mm holes). 100mm stroke length is more than needed. 75mm or even 50mm might be sufficient for some users. Alternatively [these](https://jlcmc.com/product/s/B16/BQD-JKK60/steel-linear-module-kk60-series#selection-tab) linear guides are really nice too and even can be ordered with covers, but are more expensive and use 30mm M5 bold pattern which cannot be used out of the box with the SK12 blocks.

The loadcell joints are from off-the-shelf SK12 shaft supports. They are easy to source, reasonably cheap and therefore a good buyout option. Since they are made from matel, they are likely stronger than your bones.

The beefy loadcell was choosen, as it has a M12 thread, which allows easy connection with the M12 ball joint. [These](https://s.click.aliexpress.com/e/_DFQ8bjx) loadcells are nice too, but would require adapters or redesign of the loadcell arm.

The pedal arms have a certain width to it, to reduce flex, when pedal force is applied off-centre.

As a base-plate a 2080 aluminium extrusion was chooses as it allows easy screw on of attachments as well as easy and flexible attachment to the simrig.

As a FDM material I choosed [PETG-CF](https://amzn.eu/d/00g90wIk), since the carbon fibre particales make the parts supper stiff and the PETG gives good layer bonding while having a better heat resistance than PLA.

# Overview

## Mechanical design
The mechanical design is depicted below <br>
DiyFfbPedalAssembly v61



## Alterations
Here are some nice upgrades.

### 608zz to KP08 bearing

Instead of the 608zz bearing, one can also buy two [KP08 bearing blocks](https://s.click.aliexpress.com/e/_Dk7Wokt)
and take the bearings from there. The benefit is, that they have a screw flange to remove any play between bearing and axis. An example assembly is depicted below:

.

### JKK rail

I'm currently using a [JKK60-10-P-150-A1-F4-C-M](https://jlcmc.com/product/s/B16/BQD-JKK60/steel-linear-module-kk60-series#selection-tab) on my trottle. It's noticeably quieter than the Aliexpress guide. However, it was almost 5 times as expensive inlcuding shipping and taxes. To hold the JKK rail, a 3d printable adapter is used, which can be found [here](CAD/JKK_rail_chris/Jkk_to_2080_adapter v1.stl). 

### DYLY-107 loadcell
Instead of the beefy loacell, smaller ones can be found [here](https://s.click.aliexpress.com/e/_DFQ8bjx). No immediate performance upgrade was observed. 

The thread of the DYLY-107 loadcell is M8. The beefy loadcell has a M12 thread. 

Needed changes:<br>
- Instead of using a SK12, a SK8 block fits well, e.g. [link](https://s.click.aliexpress.com/e/_okuBOQ9)
- balljoints: switch to M8 type balljoints, e.g. [link](https://s.click.aliexpress.com/e/_opZom53)
- The remaining M12 rods have to be exchanged by M8 versions.

# List of printed parts

The print orientation was choosen manually. Support was activated only for the part PedalArmLowerBar.stl.

| Part  | Quantity | Required |
| --- | --- | --- |
| [608zzHolder](../STL/608zzHolder.stl)  | 2  | yes |
| [CncModuleHolder](../STL/CncModuleHolder.stl)  | 2  | yes |
| [CncModuleHolderLeft](../STL/CncModuleHolderLeft.stl)  | 2  | yes |
| [Faceplate](../STL/Faceplate.stl)  | 1  | yes |
| [PedalArmLeft](../STL/PedalArmLeft.stl)  | 1  | yes |
| [PedalArmRight](../STL/PedalArmRight.stl)  | 1  | yes |
| [PedalArmLowerBar](../STL/PedalArmLowerBar.stl)  | 1  | yes |
| [PedalArmUpperAdapter](../STL/PedalArmUpperAdapter.stl)  | 1  | yes |
| [PCB Spacer](../STL/PcbSpacer_v1.stl)  | 2  | yes |
| [PedalSideGuard](../STL/PedalSideGuard.stl)  | 1  | no |
| [V5 PCB case lower part](../CAD/PcbV5case/V5PcbCaseLowerPart.stl)  | 1  | no |
| [V5 PCB case upper part](../CAD/PcbV5case/V5PcbCaseUpperPart.stl)  | 1  | no |

To close the 2080 extrusion front/back, the following part was printed twice: <br>
[2080 profile cap](https://makerworld.com/models/209499) 

To cover the PSU channels, thr following thing was used (recommended to print at 101% scale, since it was designed with 0% tolerance): <br>
https://www.thingiverse.com/thing:5158578

An adapter to mount the PSU to 4040/4080 aluminium extrusions can be found here: <br>
[STL](../STL/PSU/LRS_Holder.stl) <br>
[CAD](../CAD/PSU/LRS_Holder.f3d)

It requires the following screws: <br>
4x M4x8mm <br>
2x M5x15mm <br> 
2x M5 t-nut for 4040 profile <br>

# Print settings
I printed with 10 perimeters, 10 top/bottom layers, 20% infill. 270°C hotend temperature, 70°C heated bed temperature.

# Assembly instructions

Mount CNC guide to 2080 profile with:<br>
4x M4x10mm <br>
4x M5x25mm <br>
2x printed "CncModuleHolder" <br>
2x printed "CncModuleHolderLeft" <br>

Mount pedal plate to pedal arms: <br>
8x M5x30mm <br>
2x SK12 <br>

Mount 608zz adapter to 2080 profile: <br>
2x printed "608zzHolder" <br>
2x 608zz bearing <br>
M8x100 rod <br>
4x M5x10mm

Mount SK12 to linear guide:<br>
4x M4x15mm<br>
4x M4 washer<br>
2x SK12<br>

Mount iSV57 to linear guide:<br>
4x M4x15mm

Loadcell: <br>
2x M12x55mm threaded rod <br>
2x M12 nut

Loadcell to SK12: <br>
2x M12x45mm threaded rod

# Tips
To reduce any play in the system, I wrapped some layers of [teflon wrap](https://amzn.eu/d/0cYW6pJp) around the threaded rods and pushed the 608zz bearings and ball rods over it.

# Analysis results
To test the mechanical design, following test were conducted:

## Strength test
To be done! 

Perhaps FEM analysis

# CAD resources
Linear guide <br>
https://grabcad.com/library/sgx-linear-module-1

608zz <br>
https://grabcad.com/library/608-skate-board-bearing-1

iSV57 <br>
https://www.omc-stepperonline.com/de/nema-23-integrierter-easy-servo-motor-130w-3000rpm-0-45nm-63-73oz-in-20-50vdc-buerstenloser-dc-servomotor-kurze-welle-isv57t-130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

SK12 <br>
https://grabcad.com/library/sk08-shaft-support-1

2080 <br>
https://grabcad.com/library/2080-aluminium-extrusion-european-standard-t6-1

M12 female rod end <br>
https://grabcad.com/library/female-rod-end-m12-1

Loadcell  <br>
https://grabcad.com/library/m12-threaded-s-type-tension-compression-load-cell-1000kg-1

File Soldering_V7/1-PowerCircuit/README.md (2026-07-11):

# FR120

From the 2.54mm pin header 3 single pins and a two pin element was cut, see <br>
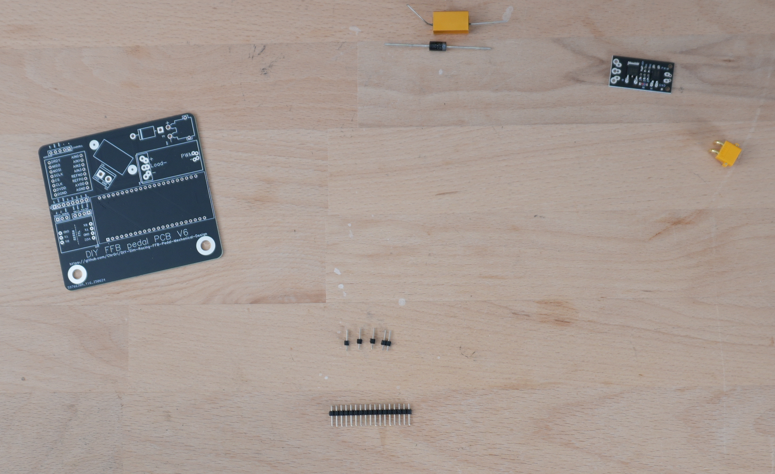
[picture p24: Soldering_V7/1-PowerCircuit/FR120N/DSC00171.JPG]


The pins were placed in the PCB as shown below.<br> 
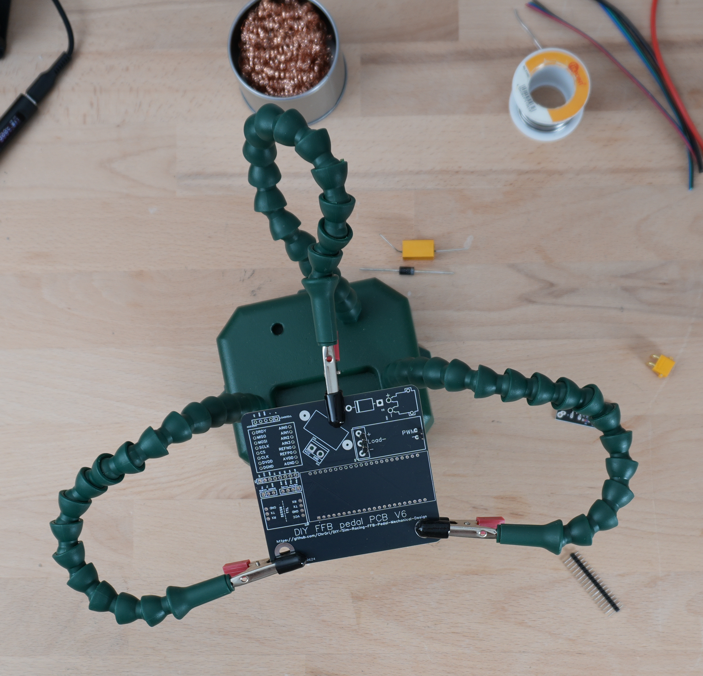
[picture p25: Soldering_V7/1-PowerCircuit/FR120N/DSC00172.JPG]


Then the FR120 was placed on top of that, see <br>
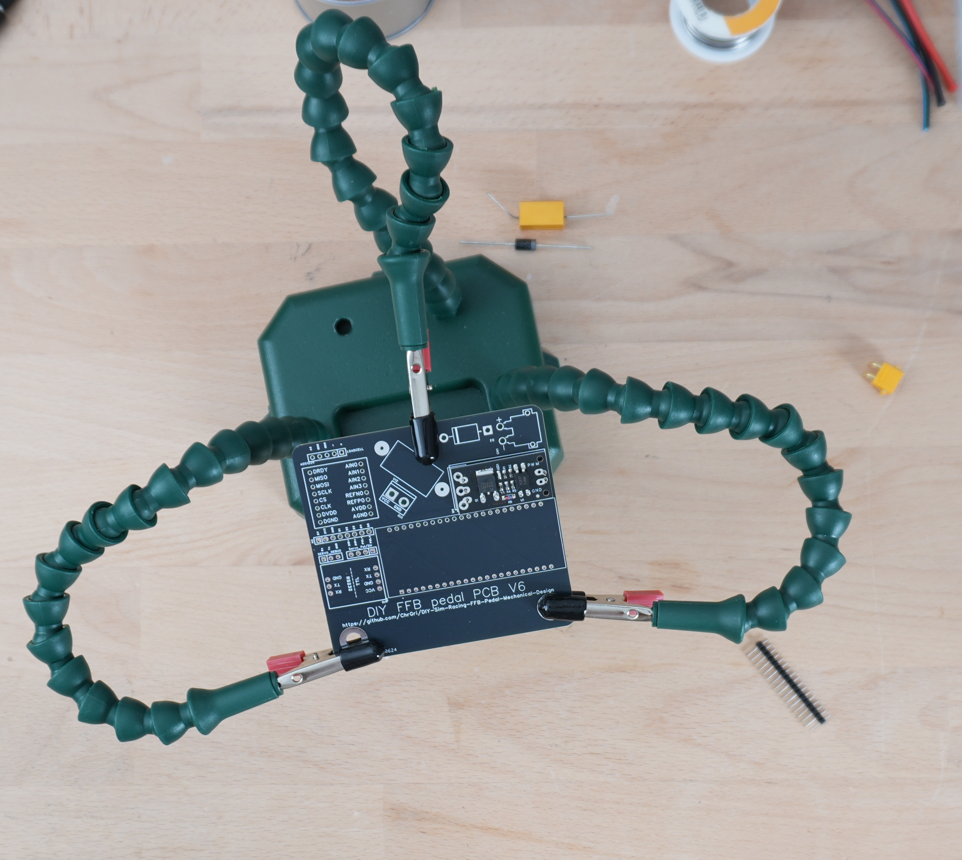
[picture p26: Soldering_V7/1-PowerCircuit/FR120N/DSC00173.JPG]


The top side was soldered first<br>
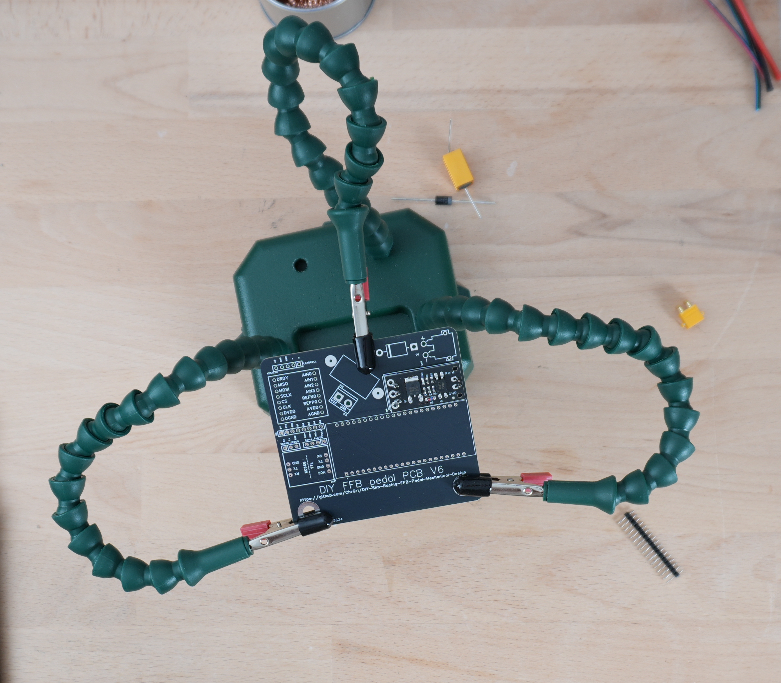
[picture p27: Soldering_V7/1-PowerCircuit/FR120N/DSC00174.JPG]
,

the bottom side afterwards<br>
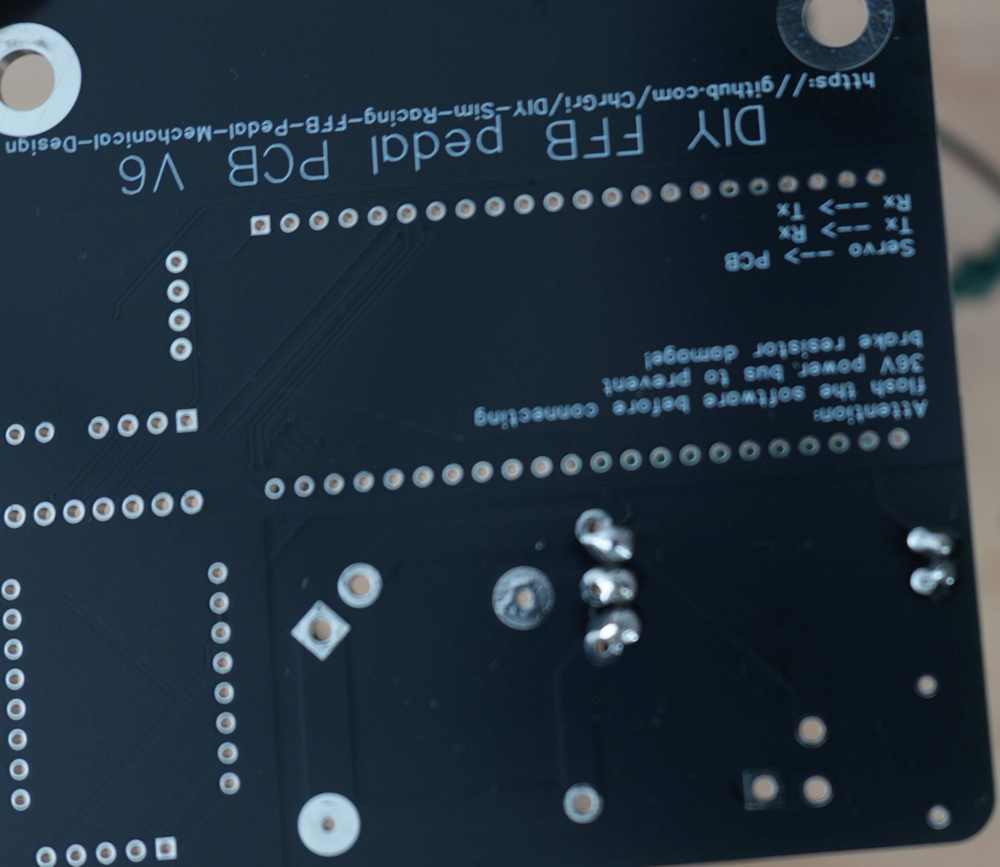
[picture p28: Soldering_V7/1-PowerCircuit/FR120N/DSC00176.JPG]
.

# SR5110
In the next stage, the SR5110 Schottky diode was soldered. The correct polarity is marked on the board. It was bend to fit through the corresponding holes<br>
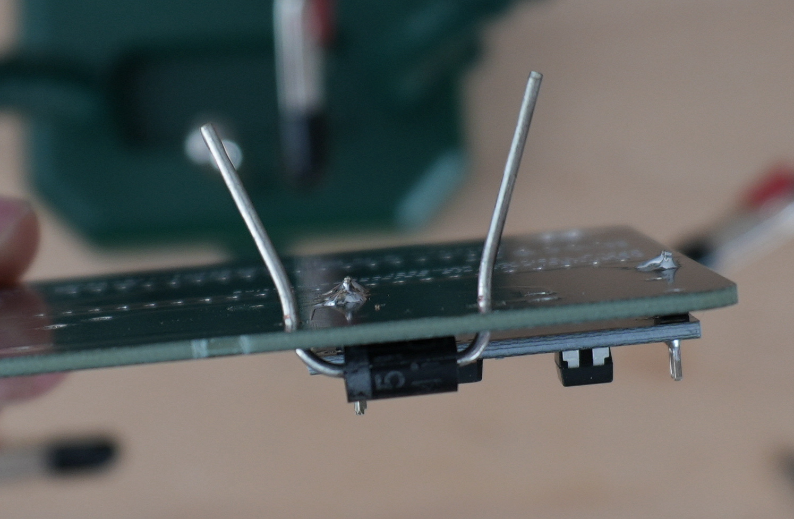
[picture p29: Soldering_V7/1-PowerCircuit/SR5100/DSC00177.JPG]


and the leads of the Schottky diode have been shortened <br>
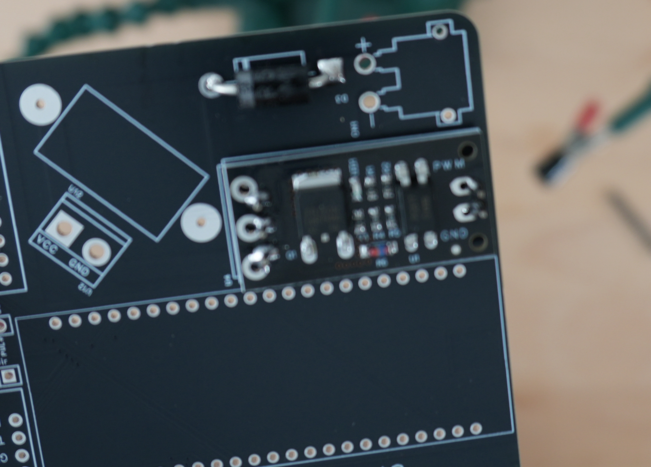
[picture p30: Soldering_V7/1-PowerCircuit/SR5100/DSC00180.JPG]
.

# Brake resistor
Similary, the brake resistor has been soldered to the board, see <br>
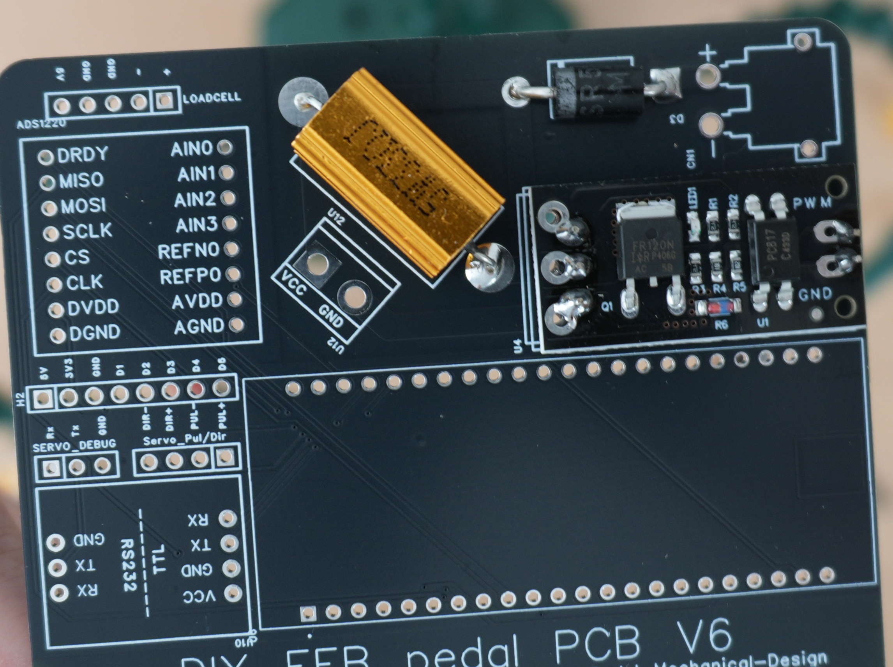
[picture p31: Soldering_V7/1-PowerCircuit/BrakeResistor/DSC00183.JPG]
 <br>
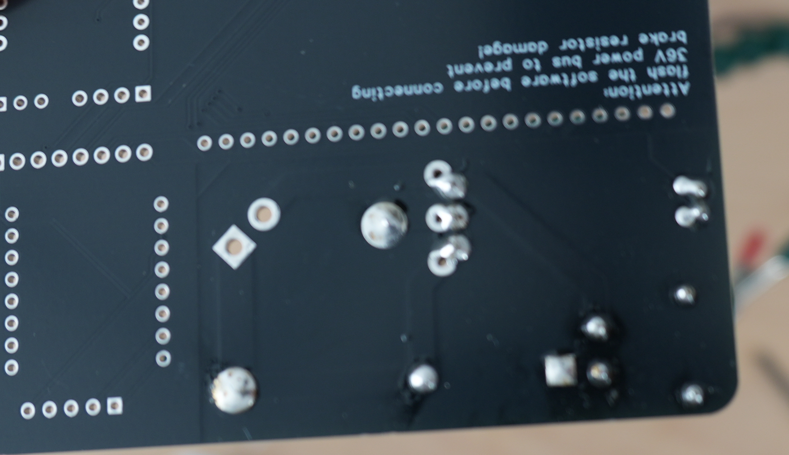
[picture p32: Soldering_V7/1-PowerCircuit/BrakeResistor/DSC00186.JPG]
.

It has no special polarity. After each step, the solder joints have been inspected visualy. 

# XT30 

Now its time to solder on the XT30 angled connector.
Just put the connector though the four corresponding holes and solder from backside, so it looks simiar to this <br>
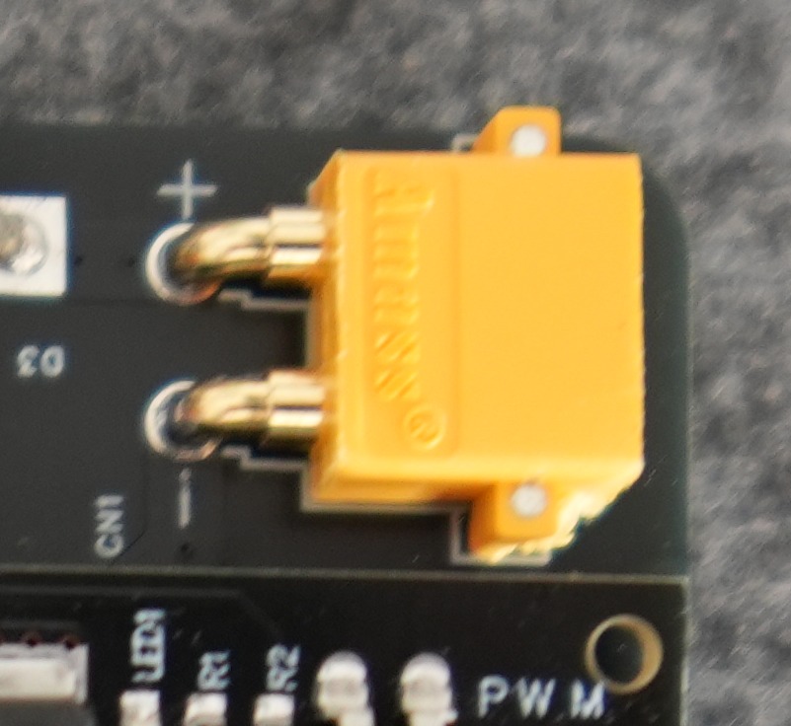
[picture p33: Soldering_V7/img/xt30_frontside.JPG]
, <br>
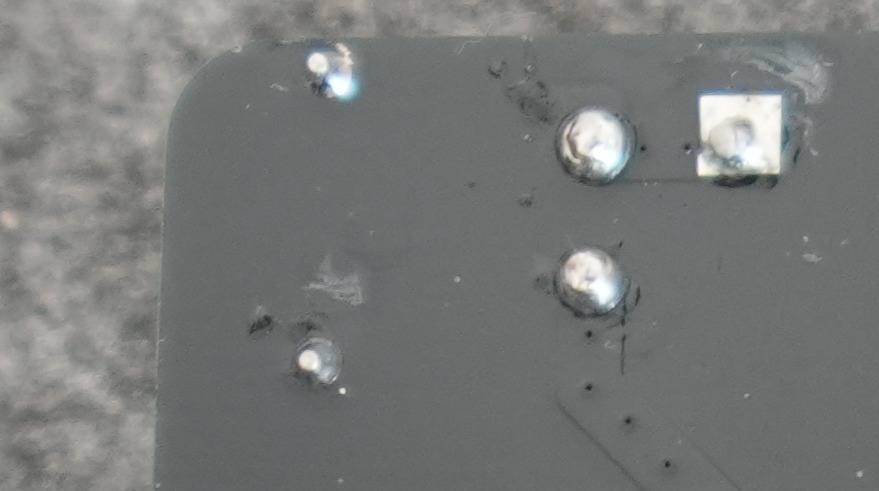
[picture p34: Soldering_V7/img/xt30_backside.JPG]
.

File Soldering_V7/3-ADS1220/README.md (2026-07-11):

# ADS1220 assembly
Correct lengt pin headers came with the ADS1220. They were placed on the PCB, see <br>
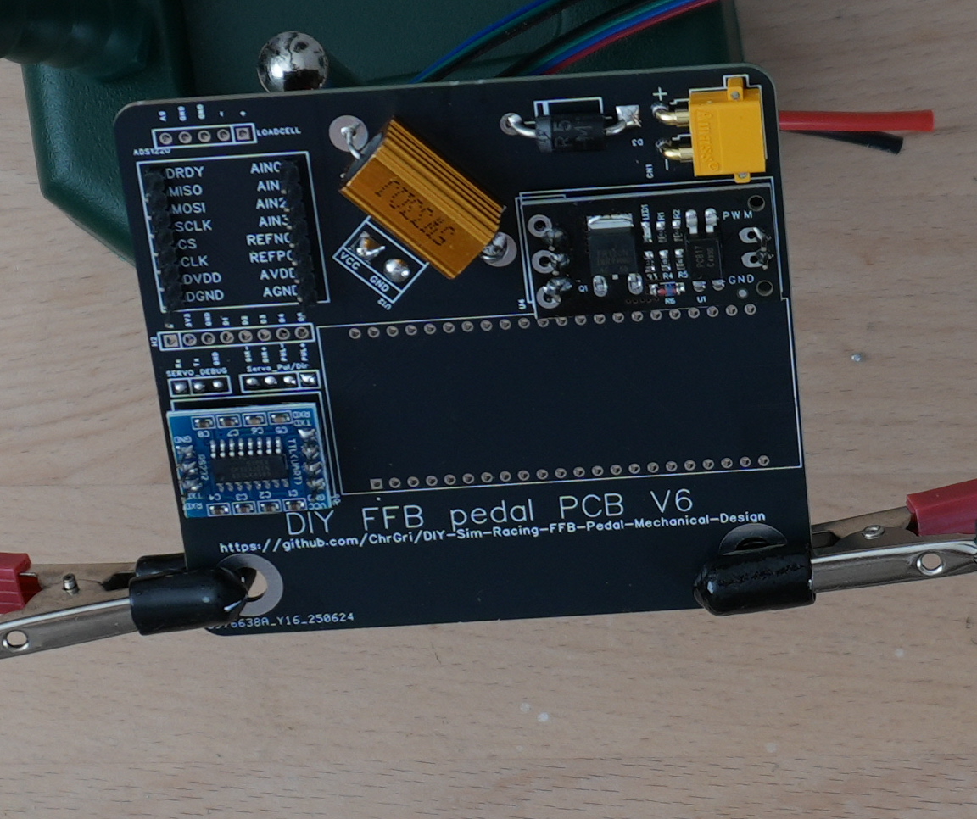
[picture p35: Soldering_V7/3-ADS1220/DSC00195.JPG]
. 

The ADS1220 was placed on the pins next <br>
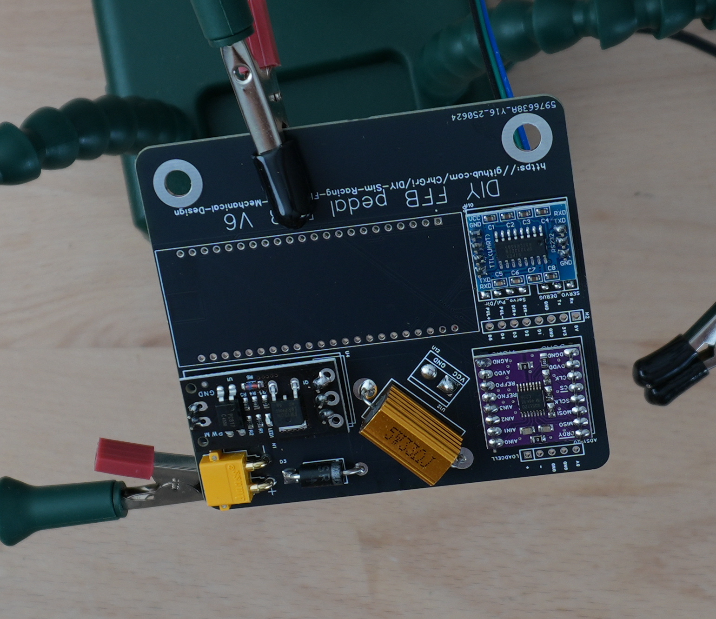
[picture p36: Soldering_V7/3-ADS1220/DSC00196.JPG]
. 

At first, the top pins have been soldered, afterwards the bottom pins were soldered. The final result is shown below <br>
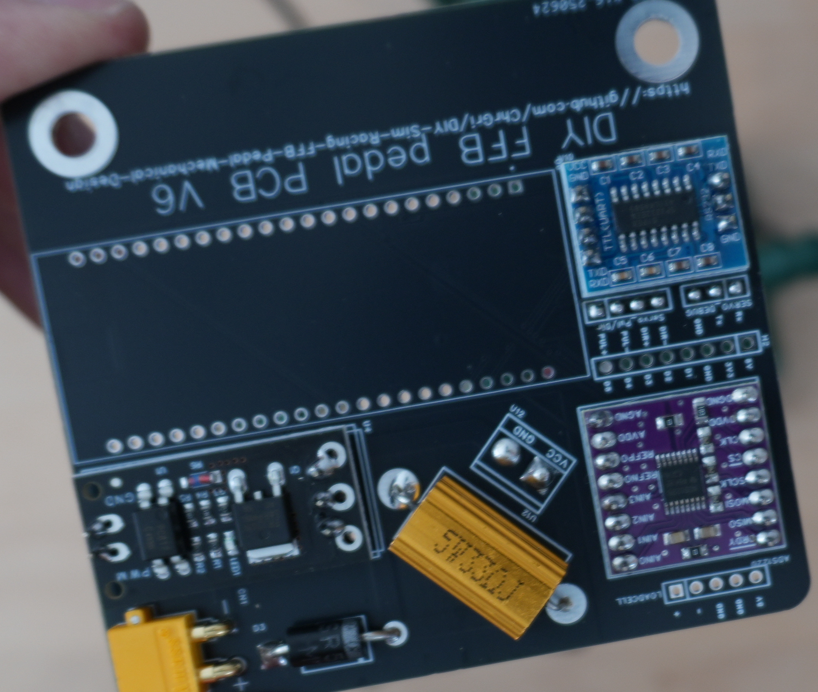
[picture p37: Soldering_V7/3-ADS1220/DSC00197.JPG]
 <br>
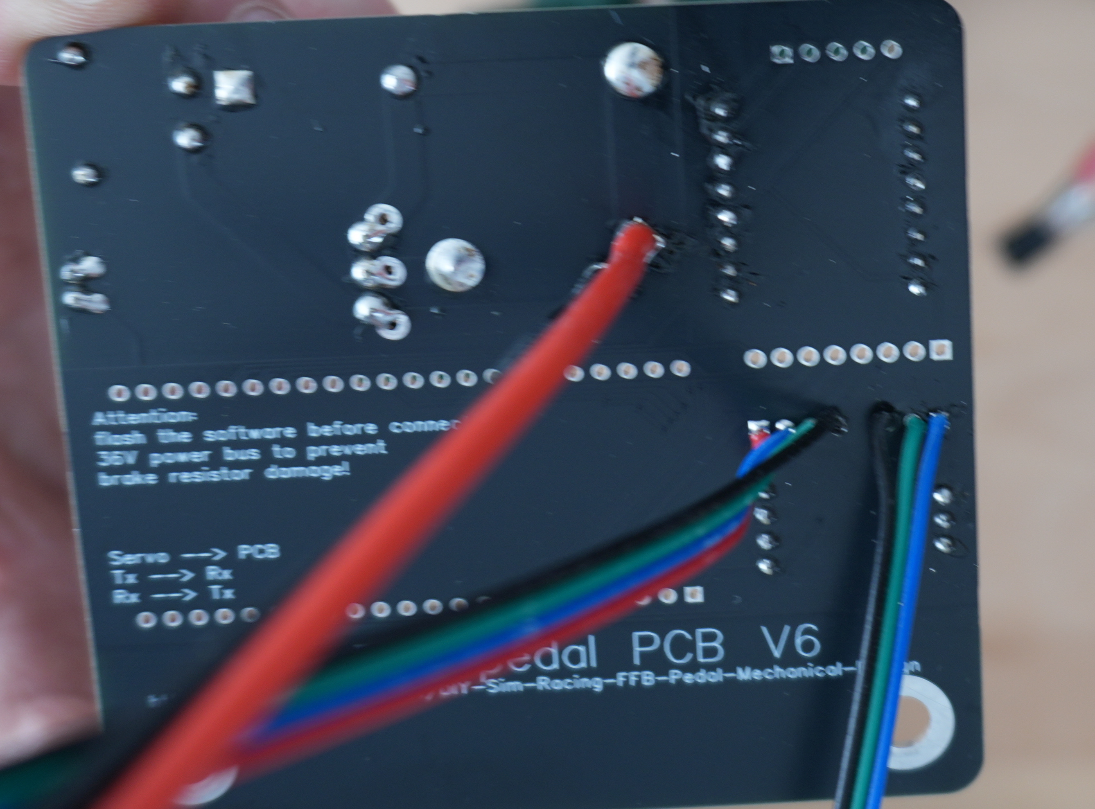
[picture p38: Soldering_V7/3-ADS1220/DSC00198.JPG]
. 

# Removing SMD resistor

In order to allow proper function, both onboard 0 Ohm SMD resistor have to be removed <br>
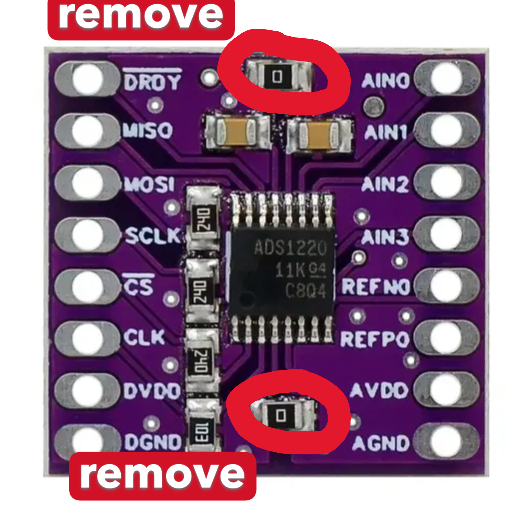
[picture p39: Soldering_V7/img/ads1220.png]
. 

It was easily done by heating up the sides of the resistor quickly.

> [!WARNING]
> If not removed, loadcell reading noise is increased because digital and analog GND are not separated, and the ESP can be damaged because 5 V and 3.3 V are shorted.

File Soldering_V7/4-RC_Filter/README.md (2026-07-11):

# 100 Ohm resistor soldering

Put the 2 100 Ohm resistors though the corresponding holes and solder them. Please follow this picture for guidance. 
After soldering, remove excessive wire from the PCB. Resistors don't have a polarity, therefore orientation is arbitrary.

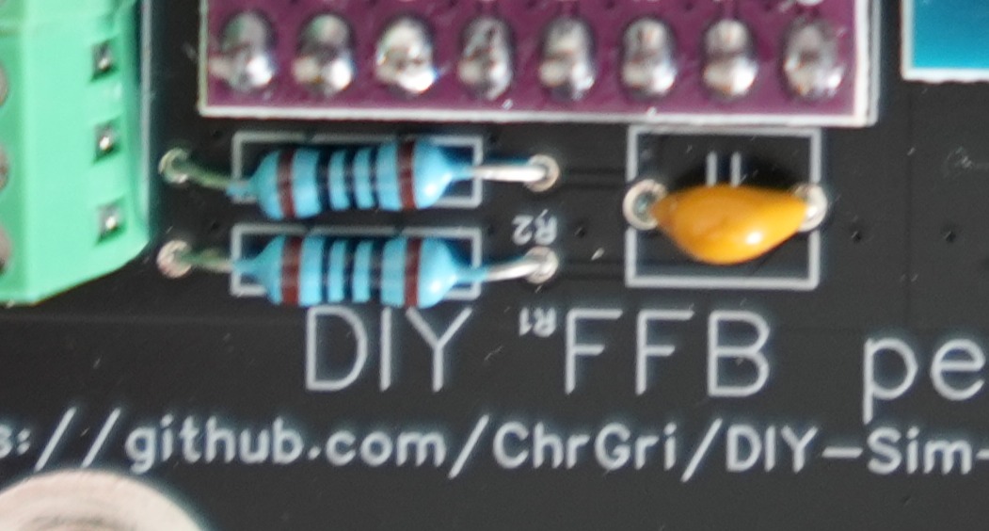
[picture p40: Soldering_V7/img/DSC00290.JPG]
.

# 100uF ceramic capacitor soldering
Put the 100uF ceramic capacitor though the corresponding hole and solder it. After soldering, remove excessive wire from the PCB. The capacitor doesn't have a polarity, therefore orientation is arbitrary.

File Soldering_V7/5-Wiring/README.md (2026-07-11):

# Screw terminal soldering

1. Remove one terminal block from the blue screw terminal, delivered with the FR120 board with a rezor blade. Be carefull not to hurt yourself. We only need two of the terminals (VCC and GND) to power the servo.

2. Solder the blue terminal to the PCB. Make sure the inport is facing outwards, so wire can be attached properly. 

3. Solder a 3 port screw terminal to PCB, later used for RS232 communication.

4. Solder 2 port and 4 port screw terminal on PCB used for servos PUL/DIR/ALM communication.

5. Solder 2 port and 3 port screw terminal to PCB later used for loadcell connection. 

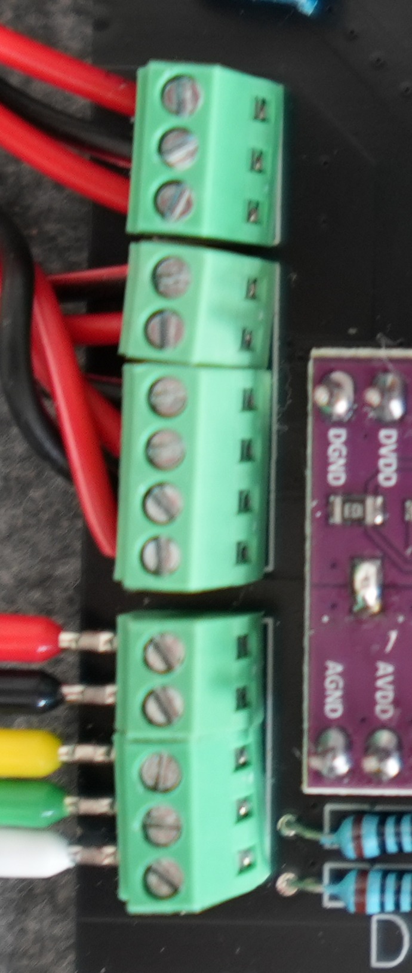
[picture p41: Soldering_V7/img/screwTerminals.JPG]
.

# Wire assembly

For wiring two power cables (AWG 18), a 3 wire and a 6 wire control cables (AWG 30) are needed. All wires were cut to 10cm length <br>

1. Connect the two AWG18 wires to the power screw terminals.

2. On the other end of the wires, connect the screw plug. Check the polarity after assembly. 

3. Connect 6 AWG 30 wires to the PUL/DIR/ALM screw terminal.

4. On the other end of the wires, connect the screw plug. Check the polarity after assembly. 

5. Connect the loadcell to the corresponding screw terminal. 

You can follow this picture to check the polarity of plugs, wires and screw terminals. <br>
.

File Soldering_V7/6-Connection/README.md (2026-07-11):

# Connect the PCB to the pedal
To fix the board to the pedal, the 3d printed [spacers](../../STL/PcbSpacer v1.stl) and two M5x15mm screws and two t-nuts nuts have been used. <br>
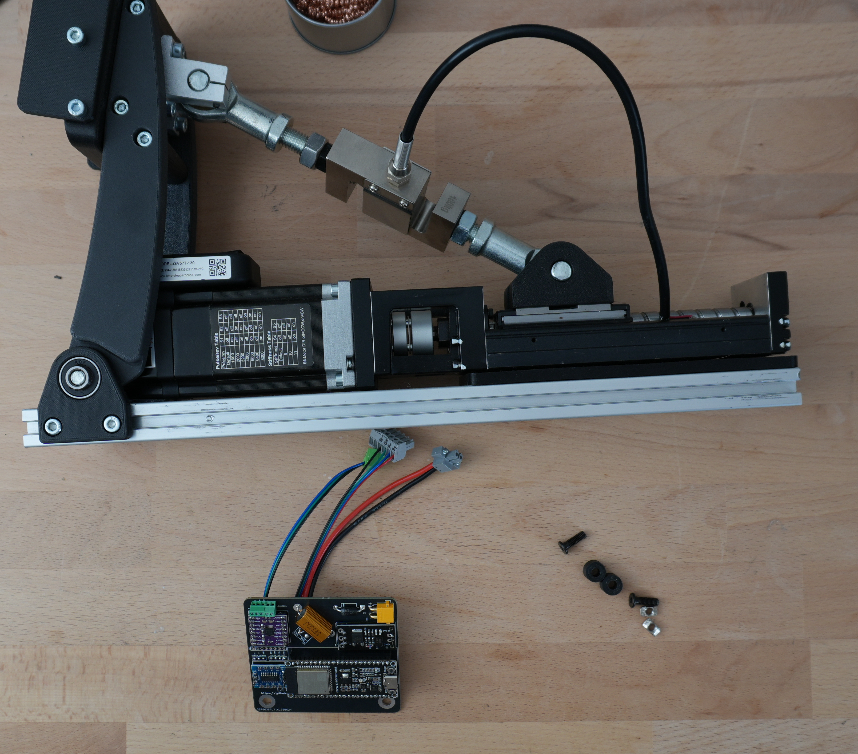
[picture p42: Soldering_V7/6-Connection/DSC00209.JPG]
 <br>
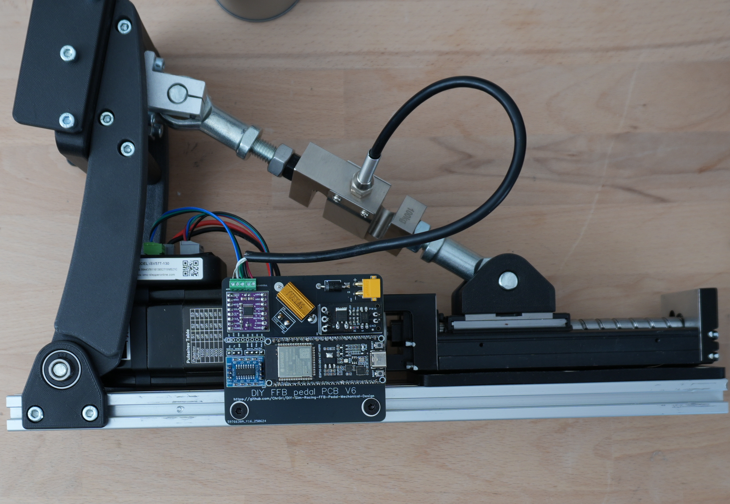
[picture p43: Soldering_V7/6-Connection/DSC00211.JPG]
.

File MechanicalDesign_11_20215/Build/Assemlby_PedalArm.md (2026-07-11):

# Important Notice (Disclaimer)
> [!NOTE]
> This guide is provided exclusively for scientific and educational purposes. It is not intended for commercial use. Building and using the device is at your own risk. No warranty is given for accuracy, completeness, or safety; illegal or dangerous applications are expressly not intended or recommended. Parts lists are provided below so results can be reproduced for documentation and research purposes.

# Introduction 
## Motivation
Originally, I built my DIY FFB pedal from metal parts. After using it for some time, I became curious whether I could create a mechanical design that is mostly 3D‑printed while remaining rigid enough to withstand the heavy loads occurring in sim racing. Furthermore, I wanted to reduce the component weight, aiming for a positive impact on pedal response time. This repository documents that journey.

The 3D‑printed design has been in use since 07/2024 and shows no signs of wear in my setup.

## Problem
Metal is typically much stronger than plastic, and FDM 3D‑printed parts are generally weaker than injection‑molded counterparts.

## Solution
Create a mechanical design that takes into account the weaknesses of FDM 3D‑printed pedal parts and reinforces typical weak points.

To minimize torsional forces on the vertical pedal arms during activation, the upper load cell joint is positioned at a similar height as the center of the pedal faceplate. A deeper analysis of the pedal kinematics can be found [here](https://github.com/ChrGri/DIY-Sim-Racing-FFB-Pedal/wiki/Pedal-kinematic).

The pedal arm has additional width to reduce flex when force is applied off‑center.

As a base plate, a 3060 aluminum extrusion was chosen, as it allows direct screw‑on attachment of the linear rail guide and flexible mounting to the sim rig.

The 3D‑printed adapters

# Table of Contents
1. Overview & Design Choices
2. CAD & STL Files
3. FEM Simulation
4. Print settings
5. Assembly Steps
	- Loadcell Arm Assembly
	- Mount iSV57 Servo to Rail
	- Mount Rail to 3060 Profile
	- Prepare Pedal Arm
	- Side Guards
	- Faceplate to Pedal Arm
	- Loadcell to Pedal Arm
	- Screw Bearing
	- Loadcell Arm to Sled
	- Rail Side Covers
	- Attach PCB

# CAD & STL Files
 <br>

The CAD model of the design can be found 
[here](CAD/DiyPedalAssemblyV3_dilatation%20v20.f3z).

# FEM Simulation
TBD.

# Print settings
For FDM printing, I chose [PETG‑CF](https://amzn.eu/d/00g90wIk), since the carbon fiber particles make the parts very stiff, and PETG provides good layer bonding while offering better heat resistance than PLA.
The PETG parts were printed with 10 perimeters, 10 top/bottom layers, and 20% infill at 270 °C hotend temperature and 70 °C bed temperature.

The 3D‑printed load cell arm adapters were printed from [83A‑TPE](https://amzn.to/4oZeoHs), which helps absorb system noise and vibration. The TPE parts were printed with 4 perimeters, 0 top/bottom layers, and 90% infill at 250 °C hotend temperature and 70 °C bed temperature.

# Assembly Steps

## Loadcell Arm Assembly
 <br>

| Design  | Info | Quantity | STL link | Amazon (affiliate) link | Aliexpress (affiliate) link |
|--|--|--|--|--|--|
| Loadcell arm (back) | 3D print | 1 |  [Loadcell arm back](STL/LoadcellArm/Loadcell-Arm-Back.stl) | | |
| Loadcell arm (front) | 3D print | 1 | [Loadcell arm back](STL/LoadcellArm/Loadcell-Arm-Front.stl) |||
| M8×16 mm cylinder head screw | | 2 | |[link](https://amzn.to/4j2gTaD) | [link](https://s.click.aliexpress.com/e/_c30VmPrT) |
| 608‑ZZ bearing | | 2 || [link](https://amzn.to/4pH0pak) | [link](https://s.click.aliexpress.com/e/_c4nGMZR7) |
| M8×45 mm threaded rod | | 2 || [link](https://amzn.to/48Iyq48) | [link](https://s.click.aliexpress.com/e/_c35xCCtj) |
| PTFE (Teflon) tape | To reduce play between rod and bearing | 1 || [link](https://amzn.to/3KzmUPj) | [link](https://s.click.aliexpress.com/e/_c3bH4vVB) |

## Mount iSV57 Servo to Rail
### Attach 8mm-to-8mm Coupler to Servo
 <br>

| Design  | Info | Quantity | STL link | Amazon (affiliate) link | Aliexpress (affiliate) link |
|--|--|--|--|--|--|
|8mm to 8mm coupler||1||[link](https://amzn.to/4qbL1CH)|[link](https://s.click.aliexpress.com/e/_c3kPwW8h)|

Target spacing between the motor flange and the coupler is approximately 5.5 mm.

### Attach Servo to Rail

 <br>

| Design  | Info | Quantity | STL link | Amazon (affiliate) link | Aliexpress (affiliate) link |
|--|--|--|--|--|--|
|KK 60 rail|JKK60-5-C-150-A1-F4-M|1|| [JLC link](https://jlcmc.com/product/s/B16/BQD-JKK60/steel-linear-actuators--kk60-series) |[Stepperonline link](https://www.omc-stepperonline.com/de/lkn60-kk-serie-kugelgewindetrieb-linearmodul-maximale-horizontale-vertikale-nutzlast-30kg-10kg-hub-60mm-lkn60-23dl050-060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)|
| M4×16 mm cylinder head screw ||4||[link](https://amzn.to/4q5GSQA)|[link](https://s.click.aliexpress.com/e/_c3bxyxud)|

## Mount Rail to 3060 Profile
 <br>
 <br>

| Design  | Info | Quantity | STL link | Amazon (affiliate) link | Aliexpress (affiliate) link |
|--|--|--|--|--|--|
|3060 adapter plate| |1| [3060 adapter](STL/3060_adapter/JKK60_to_3060_adapter.stl)|
| 3060 extrusion, 400 mm | | 1 | | [link](https://amzn.to/4aPx3Sj)| [link](https://s.click.aliexpress.com/e/_c39XbifP) |
| M5×20 mm cylinder head screws ||4| | [link](https://amzn.to/4j8jHD6)|[link](https://s.click.aliexpress.com/e/_c41gbyuD)|
| 3030 M5 spring ball nut ||4||[link](https://amzn.to/4qffsbd)| [link](https://s.click.aliexpress.com/e/_c38nyFEZ)|

## Prepare Pedal Arm
In order to increase layer strength, screws have been added across the layers. <br>
 <br>
 <br>

| Product | Info | Quantity | STL link | Amazon (affiliate) link | Aliexpress (affiliate) link |
|--|--|--|--|--|--|
| Pedal arm | 3D print | 1 |  [Pedal arm](STL/PedalArm/PedalArm.stl) | | |
|Screw 3.5mm x 30mm | To increase layer bonding | 6 | | [link](https://amzn.to/3Xv7Wwl) |[link](https://s.click.aliexpress.com/e/_c4py0Uu1)|
|Screw 3.5mm x 20mm | To increase layer bonding | 2 |  |[link](https://amzn.to/4nTd0p1) |[link](https://s.click.aliexpress.com/e/_c4py0Uu1)|
| Countersink set | To remove material for countersunk screws | 1 |  | [link](https://amzn.to/43wEfi0) |[link](https://s.click.aliexpress.com/e/_c3yAJXfL)|

## Side Guards
 <br>
 <br>

| Product  | Info | Quantity | STL link | Amazon (affiliate) link | Aliexpress (affiliate) link |
|--|--|--|--|--|--|
| Faceplate ||1|[Faceplate](STL/Faceplate/Faceplate.stl)||
| Side guards ||2|[Side Guards](STL/Faceplate/SideGuard.stl)||
|M5 x 20mm cylinder head screws ||6| | [link](https://amzn.to/4j8jHD6)|[link](https://s.click.aliexpress.com/e/_c41gbyuD)|

## Faceplate to Pedal Arm
 <br>
 <br>

| Product  | Info | Quantity | STL link | Amazon (affiliate) link | Aliexpress (affiliate) link |
|--|--|--|--|--|--|
|M5 x 30mm cylinder head screws ||2| | [link](https://amzn.to/4s0iC40)|[link](https://s.click.aliexpress.com/e/_c41gbyuD)|

## Loadcell to Pedal Arm
 <br>
 <br>

| Product  | Info | Quantity | STL link | Amazon (affiliate) link | Aliexpress (affiliate) link |
|--|--|--|--|--|--|
|Upper loadcell arm adapter | Print from TPE|2|[link](STL/UpperLoadcellArmAdapter/8mmUpperAdapter%20v4.stl)||
|M5 x 40mm cylinder head screws ||4| | [link](https://amzn.to/3MwzAqK)|[link](https://s.click.aliexpress.com/e/_c41gbyuD)|

## Attach Pedal Arm to 3060 Extrusion
 <br>
 <br>
 <br>

| Product | Info | Quantity | STL | Amazon (affiliate) link | Aliexpress (affiliate) link |
|--|--|--|--|--|--|
| Screw bearing | JS695-13-5C3L8M6 | 2 | || [link](https://s.click.aliexpress.com/e/_c41E25K1) |
| M6 x 12 x 1.6mm flat washer |  | 2 | | [link](https://amzn.to/3MFFq98)| [link](https://s.click.aliexpress.com/e/_c3Yqn9LL) |
| 3030 M6 spring ball nut ||2||[link](https://amzn.to/4pPvLeT)| [link](https://s.click.aliexpress.com/e/_c38nyFEZ)|

## Loadcell Arm to Sled
 <br>
 <br>

| Product  | Info | Quantity | STL link | Amazon (affiliate) link | Aliexpress (affiliate) link |
|--|--|--|--|--|--|
| Lower load cell arm adapter | Print from TPE | 2 | [link](STL/LowerLoadcellArmAdapter/8mmLowerAdapter_v3.stl) ||
|M5 x 25mm cylinder head screws ||4| | [link](https://amzn.to/4s0sBpY)|[link](https://s.click.aliexpress.com/e/_c41gbyuD)|

## Rail Side Covers
 <br>
 <br>

| Product  | Info | Quantity | STL link | Amazon (affiliate) link | Aliexpress (affiliate) link |
|--|--|--|--|--|--|
|Side cover left| |1|[link](STL/RailCover/Cover_left.stl)||
|Side cover right | |1|[link](STL/RailCover/Cover_right.stl)||
| M2.5 x 6mm countersunk screws||4| | [link](https://amzn.to/3MEZUyP)|[link](https://s.click.aliexpress.com/e/_c3uZ3z3F)|

## Attach 3060 Cover 
| Product  | Info | Quantity | STL link | Amazon (affiliate) link | Aliexpress (affiliate) link |
|--|--|--|--|--|--|
|Cover||2| [Cover](STL/3060EndCover/3060_cover.stl)|

## Attach PCB
 <br>
 <br>

| Product  | Info | Quantity | STL link | Amazon (affiliate) link | Aliexpress (affiliate) link |
|--|--|--|--|--|--|
|Spacer||2| [Spacer](STL/PcbSpacer/PcbSpacer%20v1.stl)|
|M5 x 20mm cylinder head screws ||2| | [link](https://amzn.to/3MwzAqK)|[link](https://s.click.aliexpress.com/e/_c41gbyuD)|

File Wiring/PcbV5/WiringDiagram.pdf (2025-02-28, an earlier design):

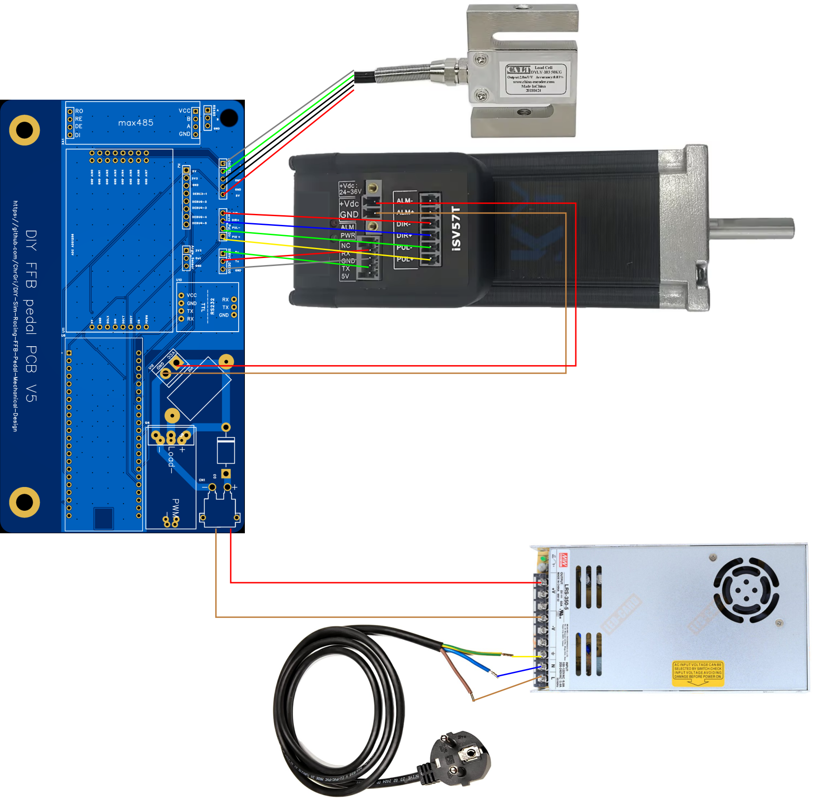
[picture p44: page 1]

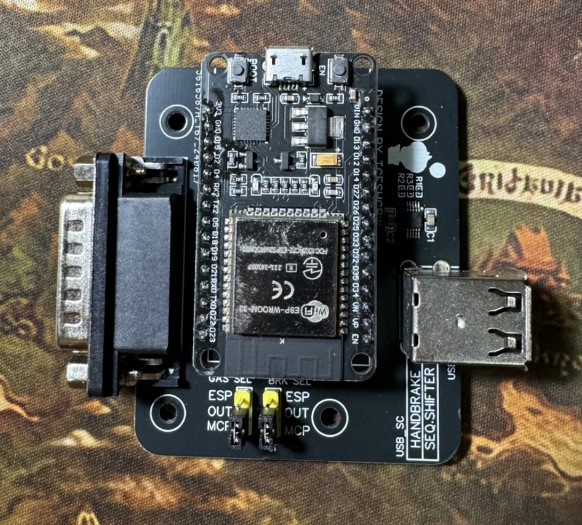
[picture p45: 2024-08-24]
Wiring/ESP32_analog_SC_D15_shield/image/PCB.jpg

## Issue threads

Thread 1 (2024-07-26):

Wrong URL for the 608zz bearings

baldisos, 2024-07-26:
Hey, i just noticed the Amazon Link for the 608zz bearing is the same as for the SK12.

Closed 2024-07-26.

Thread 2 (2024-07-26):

Loadcell type

baldisos, 2024-07-26:
The info on the Loadcell says "200kg", but when opening the Amazon link (Germany) i can only choose between 50kg, 100kg, 300kg and 2000kg.
Is the Loadcell really a 200kg one, or is that 2000kg?

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

ChrGri, 2024-07-26:
Thanks for letting me know. If corrected the link.

Closed 2024-07-26.

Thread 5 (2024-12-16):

CAD files JKK60 rail corrupt

BennyDS, 2024-12-16:
Hi

I tried opening the STP and obj files for the JKK60 rail but they are corrupt. Tried in Inventor and Autodesk online viewer.
Can you please check if they are in fact corrupt, or if there is a problem at my end.
Thank you.
Regards, Benny.

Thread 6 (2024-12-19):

Wrong link to servo debug port connector

martinhoyer, 2024-12-19:
Looks like it was introduced in [fa65fb7](https://github.com/ChrGri/DIY-Sim-Racing-FFB-Pedal-Mechanical-Design/commit/fa65fb759df5681ed7c45371a627f18b62437a5e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)- the link points to bearings, not connectors, which are at: https://www.aliexpress.com/item/1005005418641238.html

Closed 2024-12-19.

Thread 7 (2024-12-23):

pedal kinematic calculation error

dallehellstrom, 2024-12-23:
If I have the linear guide as far forward as it can go and measure to the back of the linear guide I get the number 110 mm, that is too big a number that I cannot enter into simhub kinematics (max 100mm) "pedal kinematic calculation error"

Simhub:
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

data on the current linear guide and the model I ordered
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

ChrGri, 2024-12-23:
Fixed with https://github.com/ChrGri/DIY-Sim-Racing-FFB-Pedal/commit/093751e91e8cdf91f4e09008380e3ef64e7bd885.

https://github.com/user-attachments/assets/1774331c-a27e-485d-8428-d4a2fff2f158

Will be available in the next release.

BR

Closed 2024-12-23.

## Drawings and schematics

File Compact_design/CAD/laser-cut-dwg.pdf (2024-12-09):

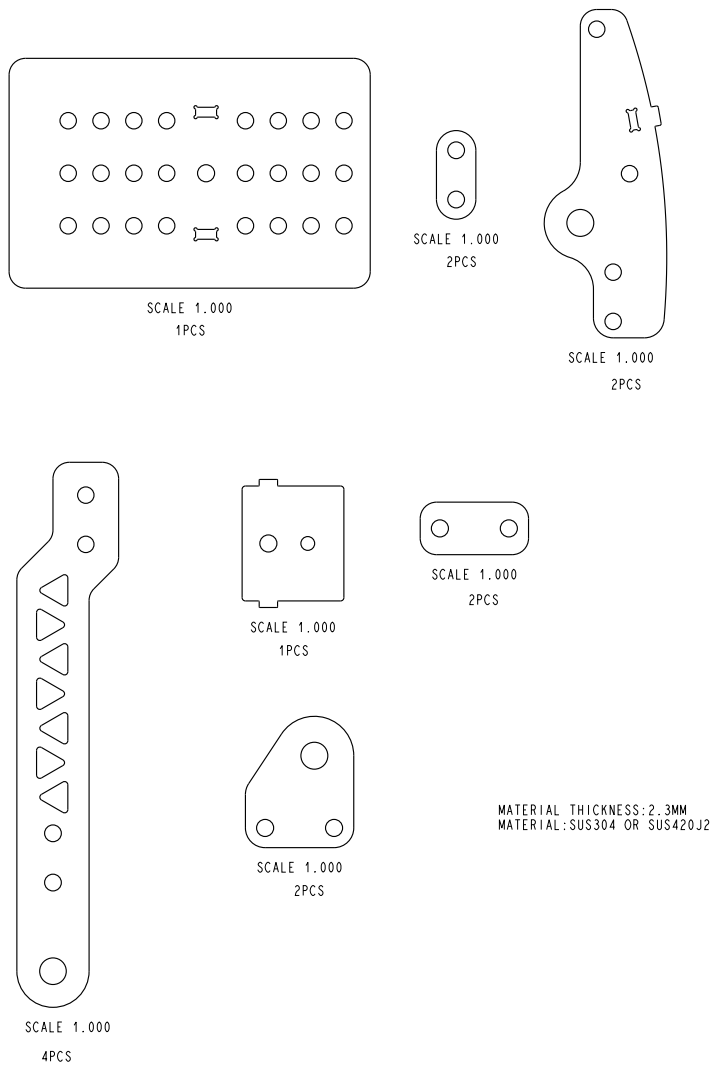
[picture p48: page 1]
1PCS; 4PCS; 2PCS; MATERIAL THICKNESS:2.3MM MATERIAL:SUS304 OR SUS420J2; SCALE 1.000

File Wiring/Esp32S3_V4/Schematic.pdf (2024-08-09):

## Pul-

## Pul+

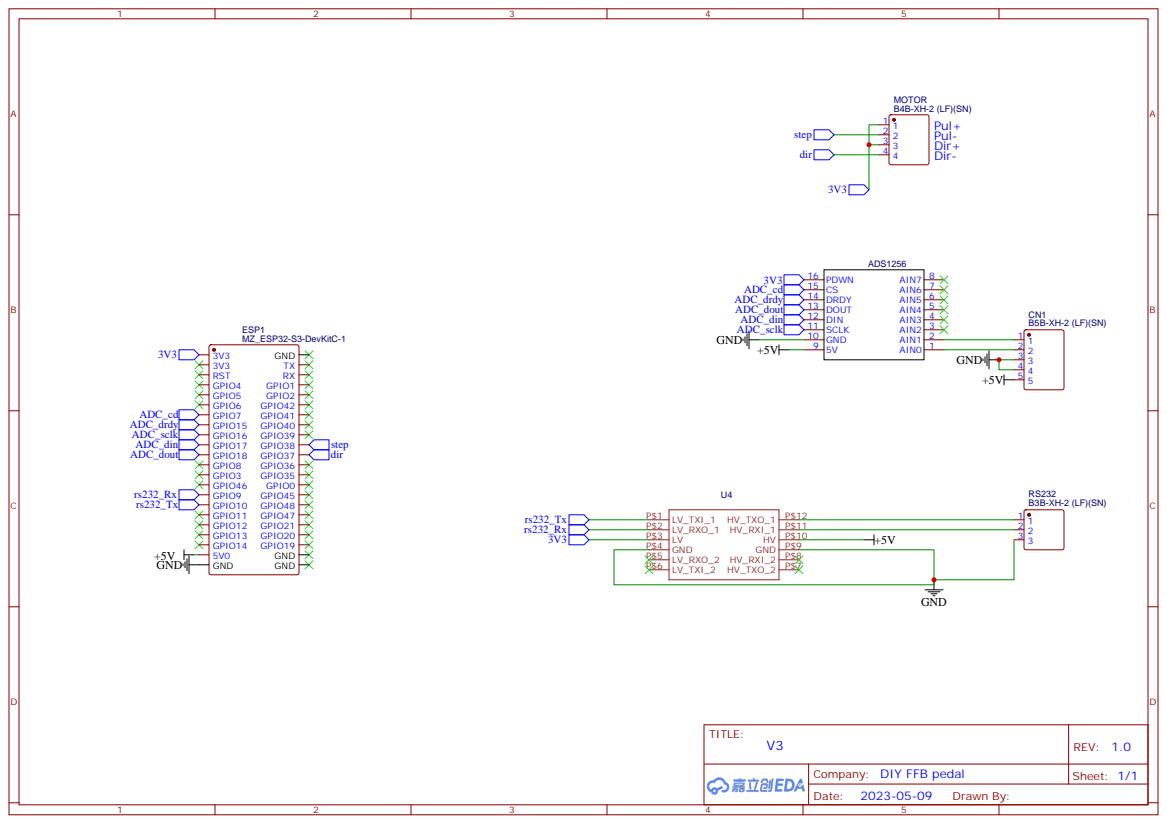
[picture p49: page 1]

GND 10 SCLK 11 DIN 12 DOUT 13 DRDY 14 CS 15 PDWN 16

Company: DIY FFB pedal

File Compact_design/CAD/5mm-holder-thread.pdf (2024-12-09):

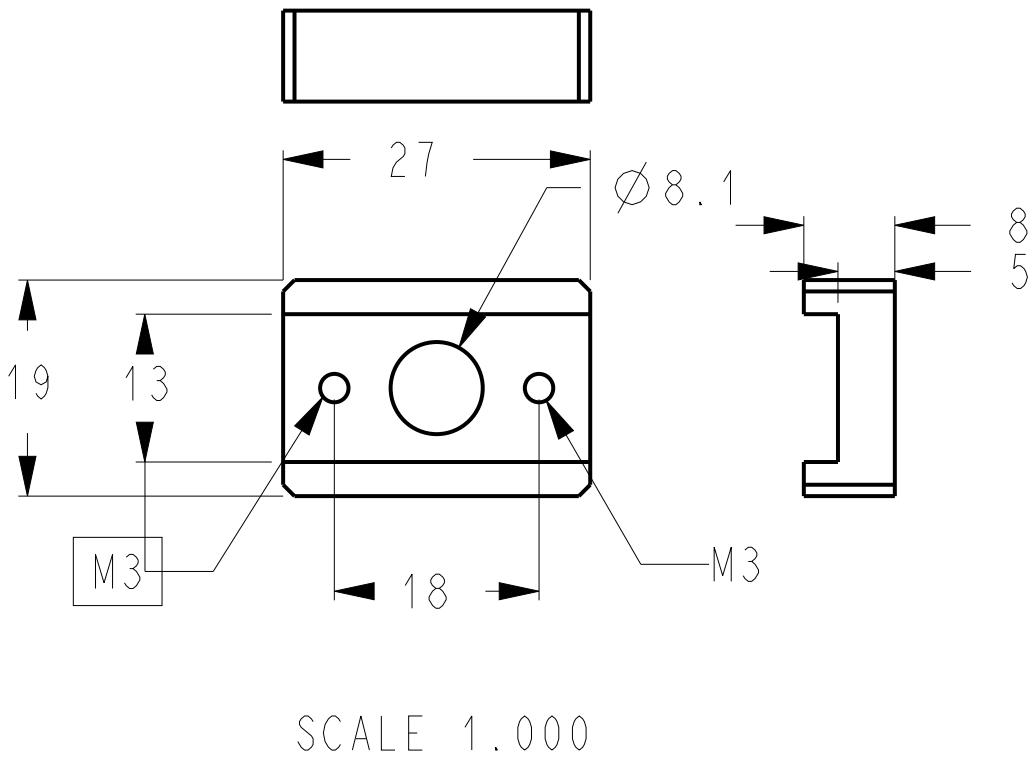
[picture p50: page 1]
SCALE 1.000

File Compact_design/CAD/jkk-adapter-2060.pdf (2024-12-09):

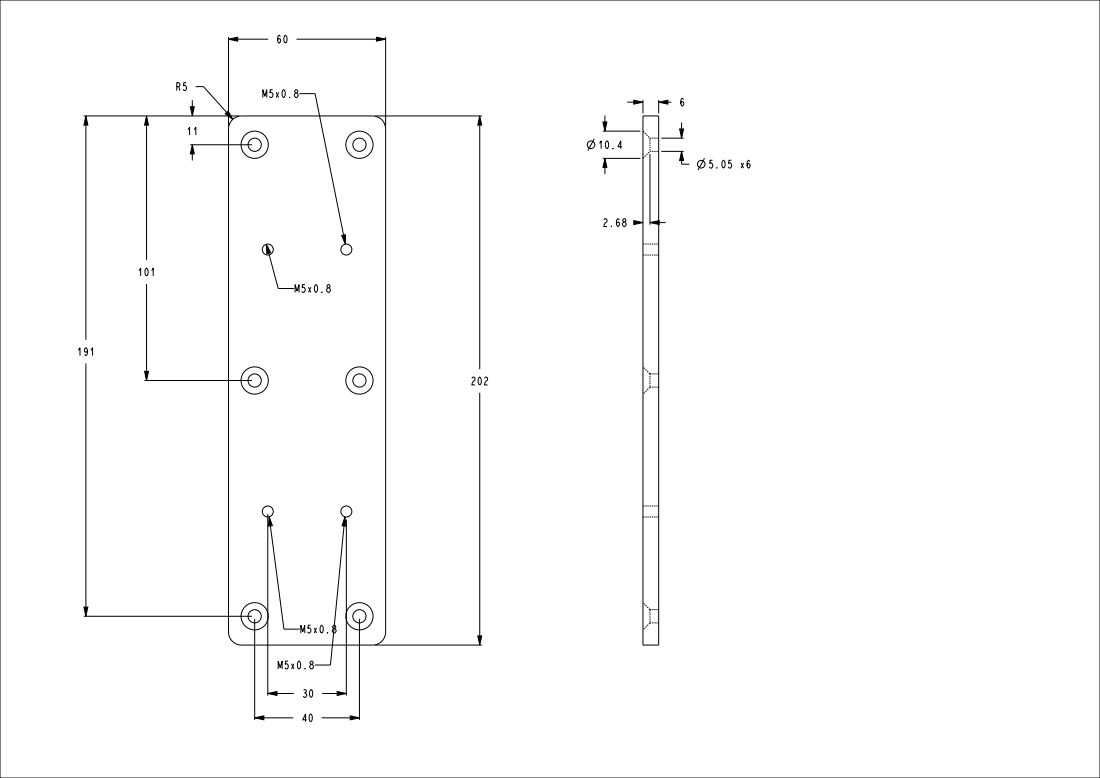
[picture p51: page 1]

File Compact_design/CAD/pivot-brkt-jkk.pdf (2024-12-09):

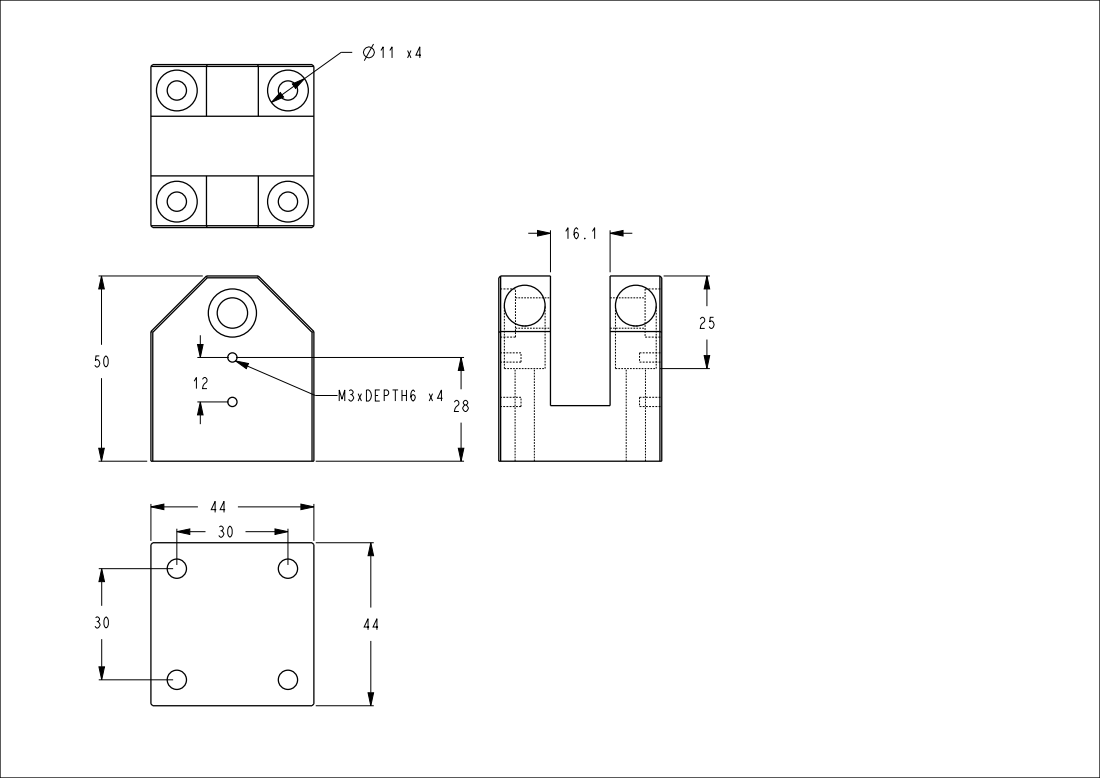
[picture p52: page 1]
M3xDEPTH6 x4

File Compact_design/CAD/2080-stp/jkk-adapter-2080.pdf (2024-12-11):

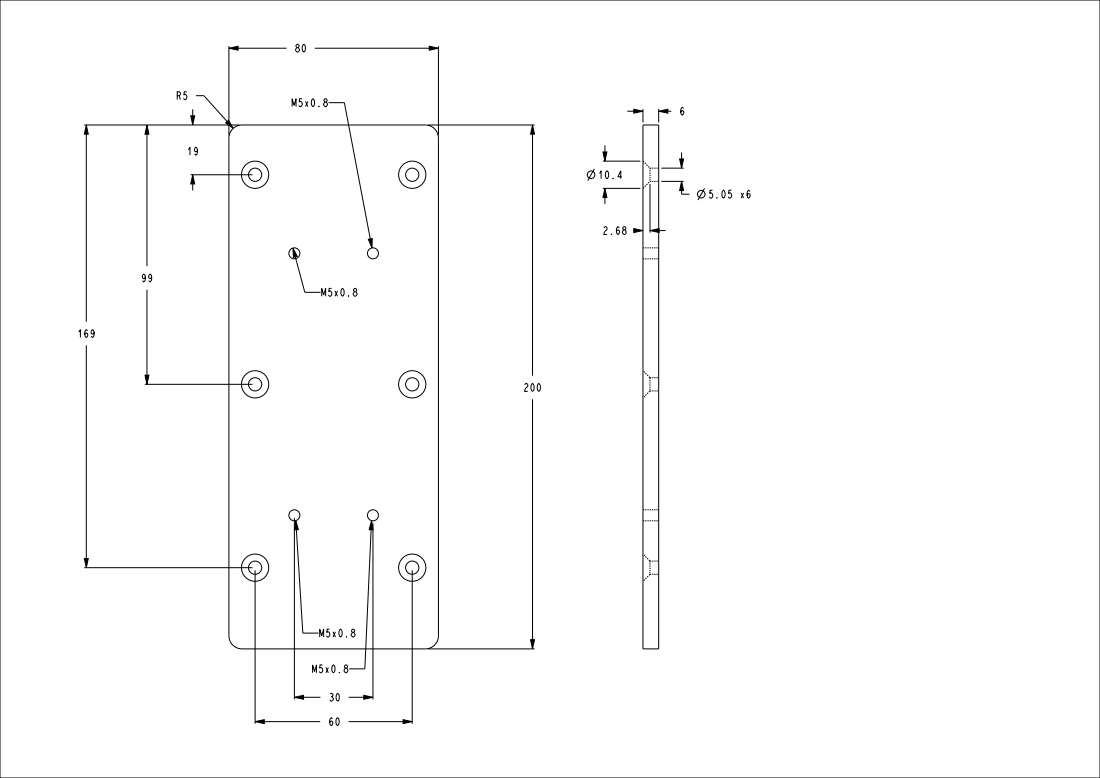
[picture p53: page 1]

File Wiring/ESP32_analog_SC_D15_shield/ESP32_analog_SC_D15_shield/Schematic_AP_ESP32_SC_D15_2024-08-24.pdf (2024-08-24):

A | A

1

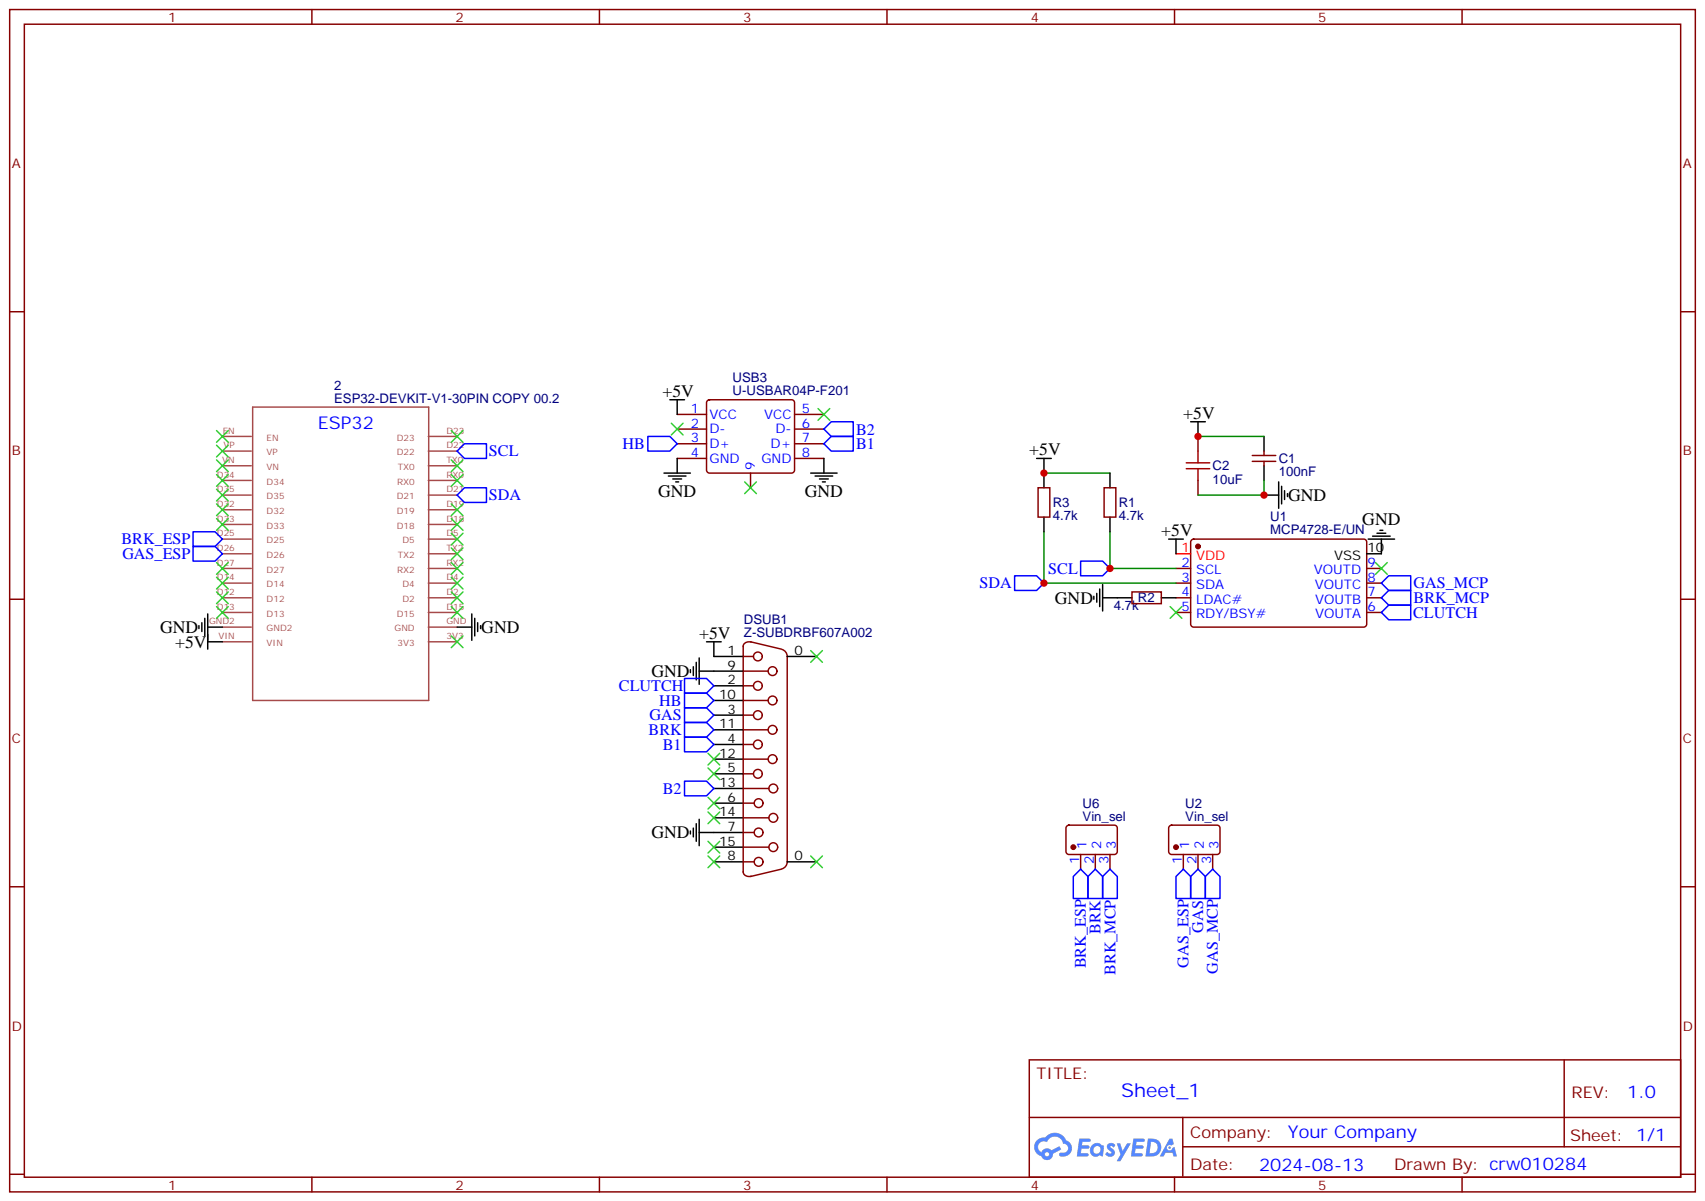
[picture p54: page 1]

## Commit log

2024-07-14 Added initial CAD model
    [DiyFfbPedalAssembly v40.f3z]
2024-07-15 Increased stiffness of pedal arms
    [DiyFfbPedalAssembly v54.f3z]
2024-07-16 Added STL
    [608zzHolder.stl, CncModuleHolder.stl, CncModuleHolderLeft.stl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]
2024-07-16 Added loadcell to CAD
    [DiyFfbPedalAssembly v54.f3z]
2024-07-31 Revision update. Include new power PCB. Increased spacing between sk8 blocks
    [608zzHolder.stl, CncModuleHolder.stl, CncModuleHolderLeft.stl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]
2024-08-09 Moved PCB design files
    [BOM_PCB_AP_tempboard.csv]
2024-08-11 Added PSU adapter
    [LRS_Holder v2.f3d, LRS_Holder v2.stl]
2024-08-11 Removed empty space in psu naming parts
    [LRS_Holder.f3d, LRS_Holder.stl]
2024-08-11 Added untested power PCB V3
2024-08-11 Removed Leadshine label from wiring diagram
2024-08-21 Added power PCB v3
2024-08-21 Changed power pcb photo
2024-08-23 Added PowerPCB V3 guard STL
    [PowerPcbV3Guard.stl]
2024-08-24 initial update for Analog_SC_D15_shield
    [BOM_AP_ESP32_SC_D15_2024-08-24.csv, BOM_PCB_AP_tempboard.csv, PickAndPlace_PCB_AP_ESP32_SC_D15_3_2024-08-24.csv]
2024-08-24 Added description for power PCB housing
2024-11-10 Added CAD files for JKK rail
    [JKK60_RailTo2080ProfileAdapter v5.f3d, JKK60_RailTo2080ProfileAdapter v5.obj, JKK60_RailTo2080ProfileAdapter v5.step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]
2024-11-10 Uploaded new design files
    [PedalArmLowerBar.stl, PowerPcbV3Guard.stl]
2024-12-09 Compact design update
    [laser-cut-dwg.dwg]
2024-12-09 add cad file for CNC
    [5MM-HOLDER-CAP.stp, 5MM-HOLDER-THREAD.stp, JKK-2060-ADAPTER.stp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]
2024-12-11 update for 2080 extrusion design
    [spacer-2-holes-20-2080.stp, spacer-2-holes-2080.stp, spacer-2-holes-25-2080.stp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]
2024-12-15 Added amazon links for power pcb
2024-12-15 Added kinematic propertied drawing
2025-01-27 Added V5 PCB
    [Jkk_to_2080_adapter v1.f3d, Jkk_to_2080_adapter v1.stl, PcbSpacer v1.f3d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]
2025-01-27 Reduced file size of brake resistor gif
2025-02-28 Bugfix wiring diagram
2025-03-24 Added JKK rail cover adapter
    [JKK60_WithCover_RailAdapter_12mm v9.f3d, JKK60_WithCover_RailAdapter_12mm v9.stl]
2025-03-29 Added pedal kinematic values in readme
2025-06-08 Added V5 PCB case
    [V5PcbCaseLowerPart.stl, V5PcbCaseUpperPart.stl, V5_PCB_case v14.f3d]
2025-07-13 Added soldering images
2025-07-13 Further readme updates
    [PcbSpacer_v1.stl]
2025-07-13 Cleanup order pcb
2025-12-16 Added 3060 profile design
    [3060_cover.stl, 8mmLowerAdapter_v3.stl, 8mmUpperAdapter v3.stl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]
2025-12-23 Added Pedal arm + rail covers
    [Cover_left.stl, Cover_right.stl, PedalArm.stl]
2026-06-01 Added V2 kinematic values
2026-06-10 Removed legacy design, split BOM into electro and mechanical parts
2026-07-11 Added v7 PCB design
2026-07-14 BOM link fix
2026-07-14 Added links to capacitors, resistors and ESP32 S3 mini
2026-10-21 Add PCB V8 gerbers, wiring diagram and wiring overview
2026-10-21 Add PCB V8 assembly guide and replace V7 guide with redirect
2026-10-21 Update BOMs for PCB V8 and add full mechanical parts list
2026-10-21 Restructure mechanical assembly guide, add PCB V8 mounting, shrink photos
2026-10-21 Add pedal configs and update SimHub plugin setup for PCB V8
2026-10-21 Rework README with banner, highlights and brake resistor module
2026-10-21 Fix list in PCB order guide and remove stray periods after images
2026-10-23 Added PCV v8 housing
2026-10-23 Added FEM analysis of pedal arm
2026-11-07 Replace the photo guide with a CAD build manual
    Add Build_Instructions.md with step-by-step renders, exploded views and
    sections, built from the new SolidCraft assembly. Move the design notes,
    print settings and real build photos over from Assembly_PedalArm.md and
    turn that page into a redirect. Keep the old section ids so the BOM links
    stay valid.
    Point the README, BOM, other guides and the PDF build at the new manual.
    Use the partner link for the PETG-CF filament and ignore CAD backup and
    lock files.
